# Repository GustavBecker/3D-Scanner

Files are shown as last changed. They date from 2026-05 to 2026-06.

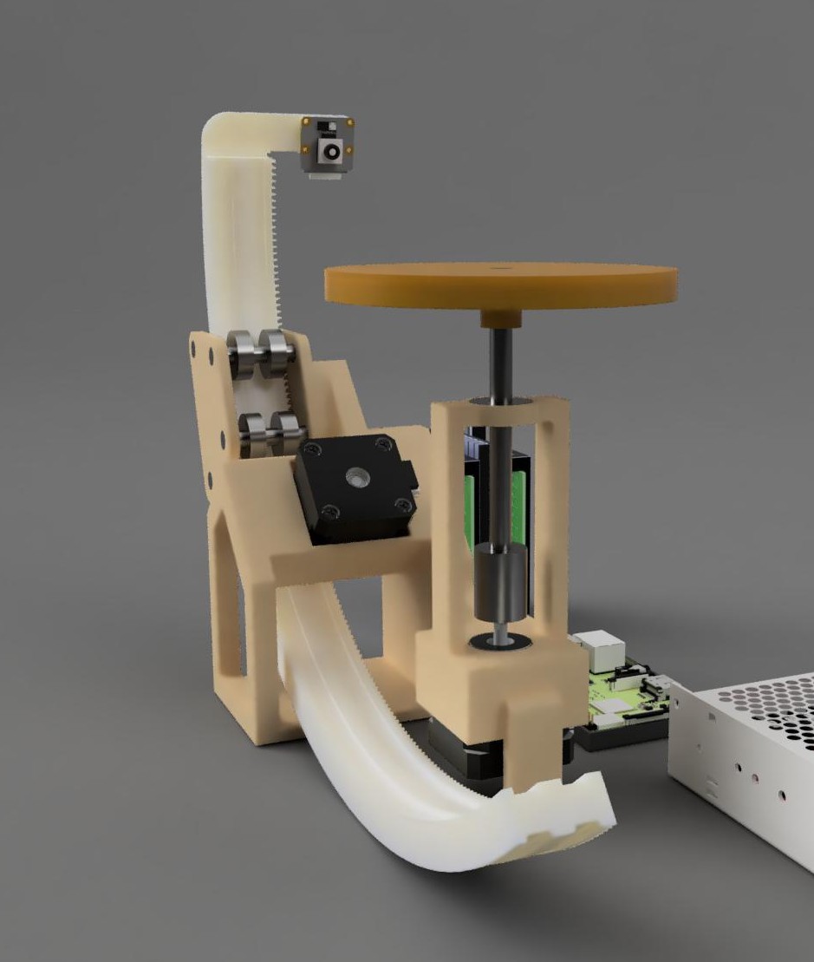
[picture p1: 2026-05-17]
Demo/Render3.jpg

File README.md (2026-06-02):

# The Ultimate hobbyist 3D Scanner!

An automated 3D scanning rig that rotates an object and tilts a camera to capture perfectly spaced photos for 3D modeling.

## About the Project
I wanted to get into 3D photogrammetry, but taking consistent photos by hand is tedious and inaccurate. To solve this, I built a completely automated, desktop scanning dome.

## How It Works
* **Brain:** A Raspberry Pi Zero 2 W controls the entire system.
* **Movement:** Dual NEMA 17 stepper motors turn the object on a turntable and tilt the camera arm up using a custom gear assembly.
* **Brain to Muscle:** High-torque TB6600 controllers drive the motors smoothly.
* **Capture:** A Raspberry Pi Camera Module 3 snaps crisp photos automatically right after the motors stop moving to avoid any blur.

A local Python script handles the timing: I have 2 stepper motors. motor1 rotates the object in the horizontal axis, stops, takes a photo, logs the position data. After a full rotation motor2 tilts the camera angle up by 10 degrees. The final image dataset is then transferred to a laptop for processing into a 3D mesh. I will use MeshRoom software on my laptop.

## How To Build
All the parts seen on the render that are not bought will be 3d printed. The bearings will be press fitted and the steppers will be held in place with M3 screws and heated inserts. The Pi Camera will be held in place with M2 screws and their heated inserts.

## Note
The xy-3606 12v to 5v 5A buck converter isn't on the model photo since there are no CAD models available to download for this module.

### Bill of Materials (BOM)

| Item | Quantity | Price (USD) | Price (ZAR) | Purchase Link |
| :--- | :---: | :---: | :---: | :--- |
| Bearings 608RS | 10 | $2.88 | R47.00 | [Buy Link](https://www.temu.com/za/-30-50-100pcs--608rs-miniature-skate-bearings--durable--9-rated-carbon-steel-rollers-for--inline-skates-and-scooters-g-601099723627836.html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) |
| TB6600 Stepper Driver | 2 | $20.61 | R336.00 | [Buy Link](https://www.temu.com/za/stepper--tb6600-upgrade-for--23--34-42-57-86--4a--9-40v-1-axis-stepping-motor-cnc-sensor-module-g-601103456762968.html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) |
| Nema 17 Stepper Motor 40mm Bipolar 2A | 2 | $30.43 | R496.00 | [Buy Link](https://www.temu.com/za/-17-stepper-motor-40mm--2a-48n-cm-66-7oz-in-42-motor-2--wire--stepper--8-degree-for--3d-printer-with-1-and-connector--17-stepper-motor-g-6011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) |
| 12v 5A Power Supply | 1 | $13.80 | R225.00 | [Buy Link](https://www.amazon.co.za/Power-Supply-Reliable-Efficient-Output/dp/B0F3TWSH3F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) |
| 5*8mm Stepper shaft connector | 1 | $2.70 | R44.00 | [Buy Link](https://www.temu.com/za/4pcs-of-motor-coupler-connectors-couplings-5mm-and-8-couplers-elastic-encoders-model-boats-model-cars-model-aircraft-metal-model-motor-connec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) |
| Raspberry Pi Zero 2 W | 1 | $26.75 | R436.00 | [Buy Link](https://www.diyelectronics.co.za/store/boards/5401-raspberry-pi-zero-2-w-rp3a0-microcontroller.html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) |
| Raspberry Pi Zero V1.3 Camera Cable 30cm | 1 | $3.50 | R57.00 | [Buy Link](https://www.diyelectronics.co.za/store/accessories/1806-raspberry-pi-zero-v13-camera-cable-30cm.html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) |
| Raspberry Pi camera module 3 | 1 | $42.02 | R685.00 | [Buy Link](https://www.communica.co.za/products/raspberry-pi-cam-module-3-orig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) |
| 20AWG wire (15.3m) | 1 | $6.32 | R103.00 | [Buy Link](https://www.temu.com/za/1pc-12-14-16-18-20-gauge-wire-12-20-awg-automotive-wire-30ft-50ft-100ft-2-conductor-red-and-black-12v-24v--cord-led-lights-remote-control-ext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) |
| SanDisk 64GB Memory Card | 1 | $12.27 | R200.00 | [Buy Link](https://www.amazon.co.za/Version-SanDisk-MicroSDXC-Memory-Adapter/dp/B073JYVKNX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) |
| 12V to 5V 5A Step Down Buck Converter | 1 | $5.34 | R87.00 | [Buy Link](https://www.temu.com/za/--24v-12v-to-5v-5a-step-down-power-supply--converter-replace--adjustable-usb-step-down-charging-module-for-phone-g-606320598027015.html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) |
| M2 Heated Inserts | 100 | $5.83 | R95.00 | [Buy Link](https://www.temu.com/za/m2-threaded-insert-self-clinching-nut-brass-knurled-internal-thread-100pcs-for-3d-printer-hardware-thermoplastics-g-606409534047817.html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) |
| M2 6mm Screws | 200 | $2.45 | R40.00 | [Buy Link](https://www.temu.com/za/m2-0-4-screw-machine-screws-pan-phillips-cross-head-screw-304-stainless-steel-fasteners-bolts-gb818-g-601105540119893.html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) |
| 8mm Dowel | 1 | $3.50 | R57.00 | [Buy Link](https://www.temu.com/za/10pcs-round-bamboo-wedges-smooth-outer-surface-0-32-inch-diameter-11-8-inch-length-bamboo-material-for-craft-making-g-606593060017181.html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) |
| **TOTAL** | | **$178.40** | **R2 908.00** | |

Main_2026-Jun-02_05-52-33PM-000_CustomizedView12948763466
Main_2026-Jun-02_05-53-24PM-000_CustomizedView17463541007
Main_2026-Jun-02_05-54-38PM-000_CustomizedView38863175261

Wiring

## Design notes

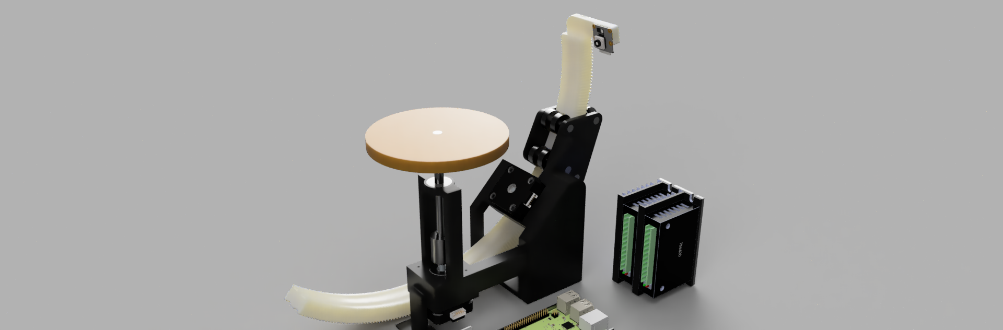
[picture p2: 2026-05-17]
Demo/Render1.PNG

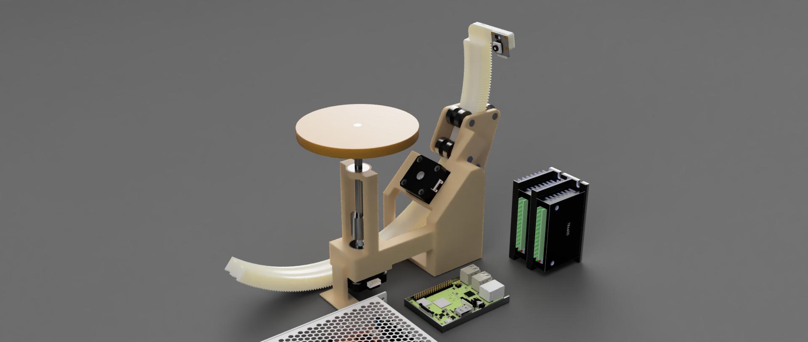
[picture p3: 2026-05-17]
Demo/Render2.jpg

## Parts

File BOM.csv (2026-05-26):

Item | Quantity | Price (USD) | Link | Price (ZAR)
Bearings 608RS | 10 | $2.88 | https://www.temu.com/za/-30-50-100pcs--608rs-miniature-skate-bearings--durable--9-rated-carbon-steel-rollers-for--inline-skates-and-scooters-g-601099723627836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 | R47.00
TB6600 Stepper Driver | 2 | $20.61 | https://www.temu.com/za/stepper--tb6600-upgrade-for--23--34-42-57-86--4a--9-40v-1-axis-stepping-motor-cnc-sensor-module-g-601103456762968.html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 | R336.00
Nema 17 Stepper Motor 40mm Bipolar 2A | 2 | $30.43 | https://www.temu.com/za/-17-stepper-motor-40mm--2a-48n-cm-66-7oz-in-42-motor-2--wire--stepper--8-degree-for--3d-printer-with-1-and-connector--17-stepper-motor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 | R496.00
12v 5A Power Supply | 1 | $13.80 | https://www.amazon.co.za/Power-Supply-Reliable-Efficient-Output/dp/B0F3TWSH3F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 | R225.00
5*8mm Stepper shaft connector | 1 | $2.70 | https://www.temu.com/za/4pcs-of-motor-coupler-connectors-couplings-5mm-and-8-couplers-elastic-encoders-model-boats-model-cars-model-aircraft-metal-model-motor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 | R44.00
Raspberry Pi Zero 2 W | 1 | $26.75 | https://www.diyelectronics.co.za/store/boards/5401-raspberry-pi-zero-2-w-rp3a0-microcontroller.html | R436.00
Raspberry Pi Zero V1.3 Camera Cable 30cm | 1 | $3.50 | https://www.diyelectronics.co.za/store/accessories/1806-raspberry-pi-zero-v13-camera-cable-30cm.html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 | R57.00
Raspberry Pi camera module 3 | 1 | $42.02 | https://www.communica.co.za/products/raspberry-pi-cam-module-3-orig?variant=49198622769452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 | R685.00
20AWG wire (15.3m) | 1 | $6.32 | https://www.temu.com/za/1pc-12-14-16-18-20-gauge-wire-12-20-awg-automotive-wire-30ft-50ft-100ft-2-conductor-red-and-black-12v-24v--cord-led-lights-remote-cont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 | R103.00
SanDisk 64GB Memory Card | 1 | $12.27 | https://www.amazon.co.za/Version-SanDisk-MicroSDXC-Memory-Adapter/dp/B073JYVKNX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 | R200.00
12V to 5V 5A Step Down Buck Converter | 1 | $5.34 | https://www.temu.com/za/--24v-12v-to-5v-5a-step-down-power-supply--converter-replace--adjustable-usb-step-down-charging-module-for-phone-g-606320598027015.htm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 | R87.00
M2 Heated Inserts | 100 | $5.83 | https://www.temu.com/za/m2-threaded-insert-self-clinching-nut-brass-knurled-internal-thread-100pcs-for-3d-printer-hardware-thermoplastics-g-606409534047817.ht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 | R95.00
M2 6mm Screws | 200 | $2.45 | https://www.temu.com/za/m2-0-4-screw-machine-screws-pan-phillips-cross-head-screw-304-stainless-steel-fasteners-bolts-gb818-g-601105540119893.html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 | R40.00
8mm Dowel | 1 | $3.50 | https://www.temu.com/za/10pcs-round-bamboo-wedges-smooth-outer-surface-0-32-inch-diameter-11-8-inch-length-bamboo-material-for-craft-making-g-606593060017181.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 | R57.00
 | TOTAL | $178.40 |  | R2 908.00

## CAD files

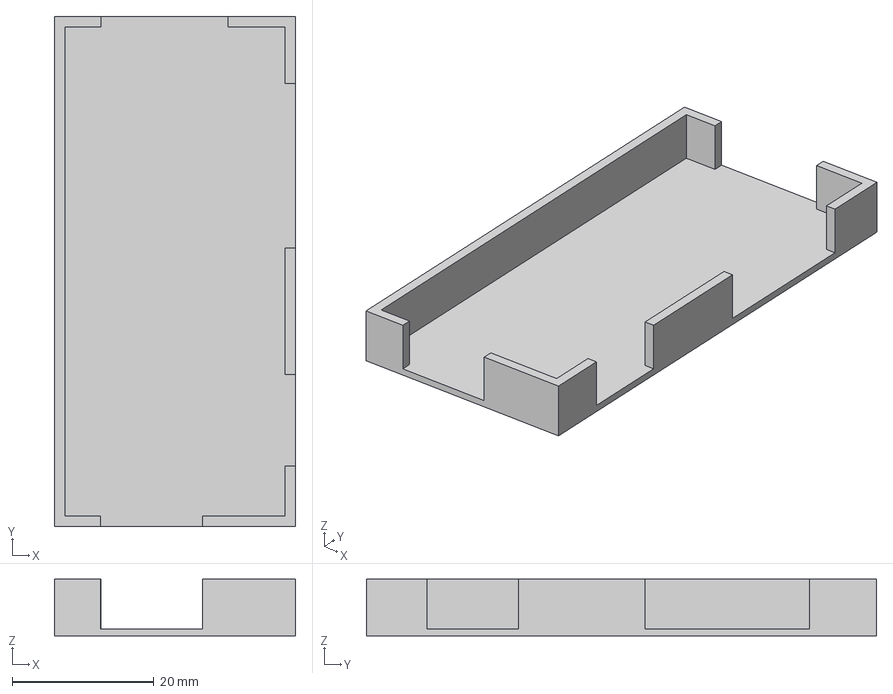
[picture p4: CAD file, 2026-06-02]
CAD/Seperate Parts/RaspberryPi_ZeroW2Holder.step
34.0 x 72.0 x 8.00 mm

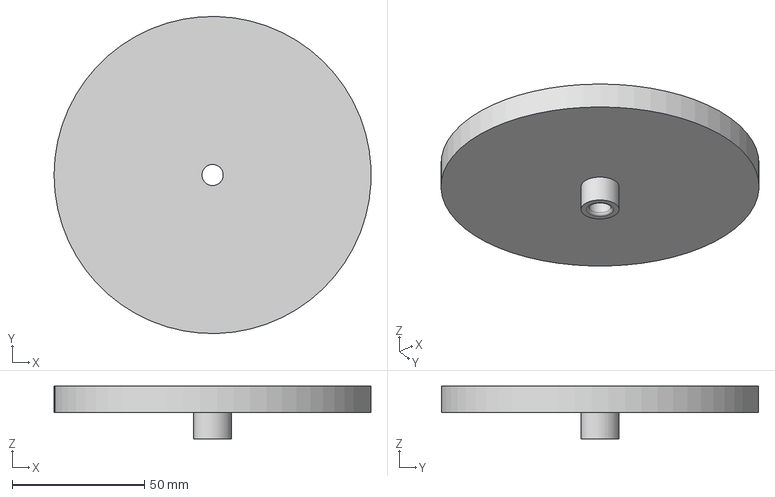
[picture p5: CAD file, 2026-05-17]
CAD/Seperate Parts/TurningTable.step
119.9 x 120.0 x 20.0 mm

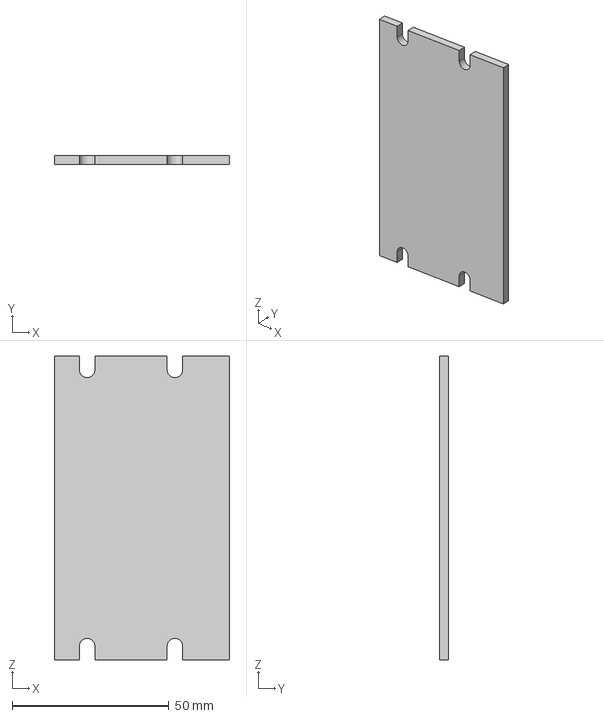
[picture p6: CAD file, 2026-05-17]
CAD/Seperate Parts/TB6600_ConnectorPlate.step
56.0 x 3.00 x 97.0 mm

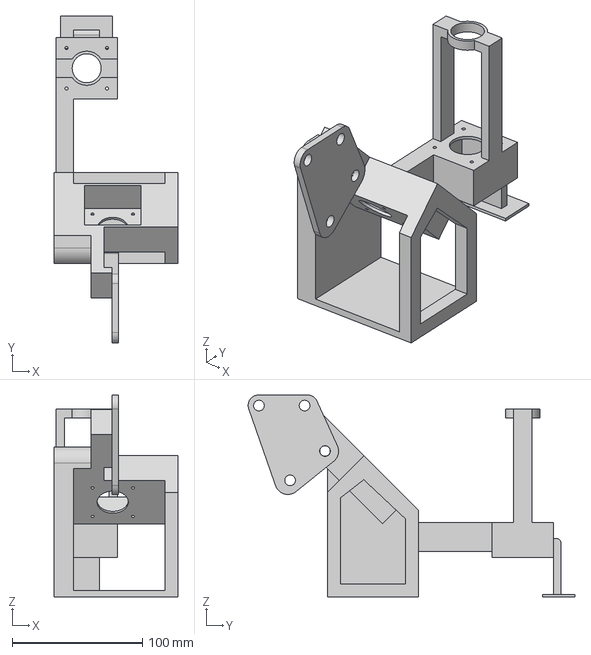
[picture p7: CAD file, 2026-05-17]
CAD/Seperate Parts/BaseStructure.step
95.0 x 250.7 x 155.0 mm

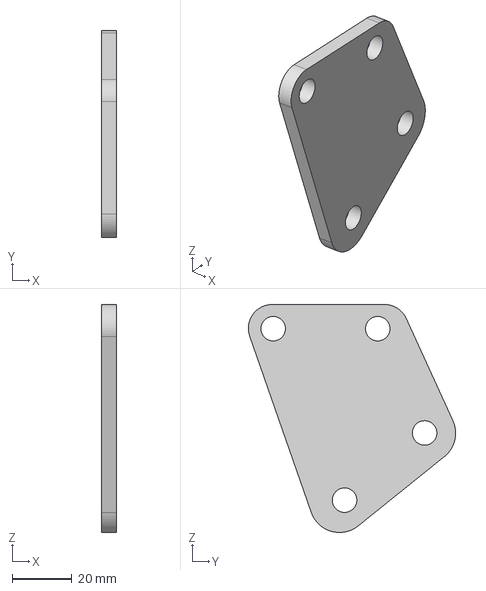
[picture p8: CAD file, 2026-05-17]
CAD/Seperate Parts/SmoothRailingConnectorPlate.step
5.00 x 69.4 x 76.3 mm

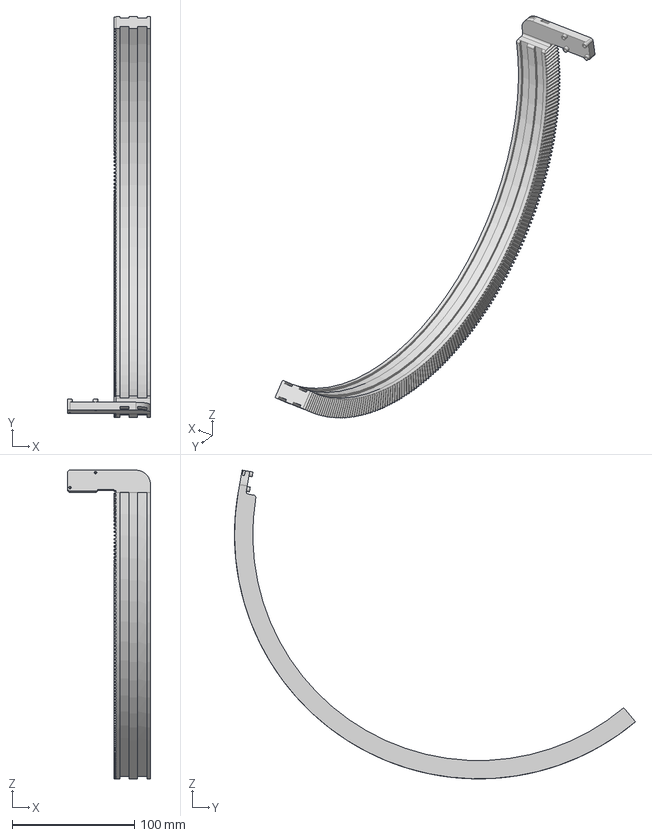
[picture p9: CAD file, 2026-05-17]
CAD/Seperate Parts/CameraRollingAxis.step
68.0 x 328.6 x 253.0 mm

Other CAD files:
CAD/Assembly.f3z

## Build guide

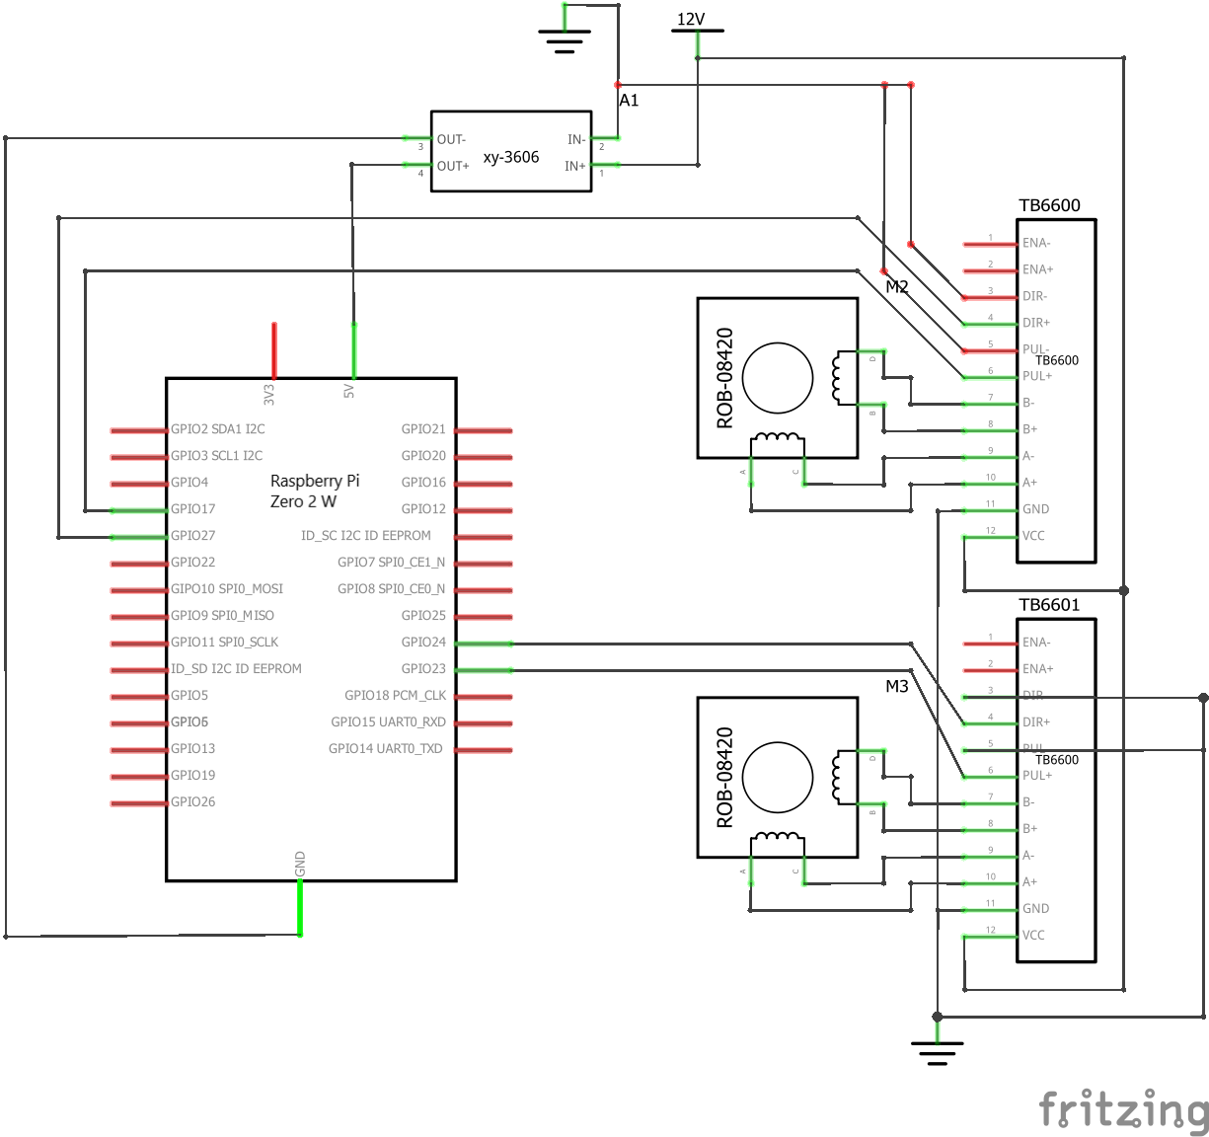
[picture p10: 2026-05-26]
WiringDiagram/Wiring.png

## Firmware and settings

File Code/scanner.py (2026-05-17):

import RPi.GPIO as GPIO
import time
import subprocess
import os

# Pin assignments
TURN_STEP_PIN = 24
TURN_DIR_PIN = 23

TILT_STEP_PIN = 17
TILT_DIR_PIN = 27

# Adjusted based on the TB6600 DIP switch settings
STEPS_PER_ROTATION_TURN = 1600  
STEPS_PER_DEGREE_TILT = 4.44  # (Total steps for a full 360 tilt circle / 360)

# SCANNING SETTINGS
NUM_PHOTOS_PER_ROTATION = 36  # Takes a photo every 10 degrees of rotation
TILT_INCREMENT_DEGREE = 10    # Amount to tilt up after a full rotation
MAX_TILT_STEPS = 5            # Number of rows to scan upwards

# SETUP GPIO
GPIO.setmode(GPIO.BCM)
GPIO.setup([TURN_STEP_PIN, TURN_DIR_PIN, TILT_STEP_PIN, TILT_DIR_PIN], GPIO.OUT)

# Ensure output directory exists
output_dir = "/home/pi/3d_scan_images"
os.makedirs(output_dir, exist_ok=True)

def pulse_motor(step_pin, steps, delay=0.001):
    """Sends PWM-like pulses to move the stepper motor."""
    for _ in range(steps):
        GPIO.output(step_pin, GPIO.HIGH)
        time.sleep(delay)
        GPIO.output(step_pin, GPIO.LOW)
        time.sleep(delay)

def capture_photo(filename):
    """Triggers the Pi Camera Module 3 to capture an image."""
    print(f"Capturing: {filename}")
    # Uses the official Libcamera command line tool to snap a quick high-res photo
    cmd = f"libcamera-still -o {output_dir}/{filename} --immediate --nopreview"
    subprocess.run(cmd, shell=True)
    time.sleep(0.5) # Settling time after photo

try:
    print("Starting 3D Scan Sequence...")
    
    # Set initial directions (HIGH/LOW depends on mechanical mounting)
    GPIO.output(TURN_DIR_PIN, GPIO.HIGH) 
    GPIO.output(TILT_DIR_PIN, GPIO.HIGH)

    steps_per_photo_turn = int(STEPS_PER_ROTATION_TURN / NUM_PHOTOS_PER_ROTATION)
    steps_per_tilt_increment = int(TILT_INCREMENT_DEGREE * STEPS_PER_DEGREE_TILT)

    for tilt_row in range(MAX_TILT_STEPS):
        current_tilt_angle = tilt_row * TILT_INCREMENT_DEGREE
        print(f"\n--- Scanning Row {tilt_row + 1} at Tilt Angle: {current_tilt_angle}° ---")

        for photo_num in range(NUM_PHOTOS_PER_ROTATION):
            current_turn_angle = photo_num * (360 / NUM_PHOTOS_PER_ROTATION)
            
            # 1. Take a picture at current position
            filename = f"row_{tilt_row}_angle_{int(current_turn_angle)}.jpg"
            capture_photo(filename)
            
            # 2. Turn the turntable to the next slice
            if photo_num < (NUM_PHOTOS_PER_ROTATION - 1): # Don't turn after the last photo
                pulse_motor(TURN_STEP_PIN, steps_per_photo_turn)
                time.sleep(0.2) # Allow vibration to settle before next loop

        # One full turntable rotation complete! Now tilt up.
        if tilt_row < (MAX_TILT_STEPS - 1):
            print(f"Rotation complete. Tilting up {TILT_INCREMENT_DEGREE} degrees...")
            pulse_motor(TILT_STEP_PIN, steps_per_tilt_increment)
            time.sleep(0.5) # Wait for tilt arm settling

    print("\nScan complete! All images saved to /home/pi/3d_scan_images")

except KeyboardInterrupt:
    print("\nScan aborted by user.")

finally:
    GPIO.cleanup()
